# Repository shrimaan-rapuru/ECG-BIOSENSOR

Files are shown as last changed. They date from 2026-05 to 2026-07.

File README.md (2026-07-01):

# ❤️ ECG Biosensor Platform

A low-cost, real-time ECG signal acquisition and analysis platform built from a SparkFun AD8232 and an Arduino Uno R4 Minima — designed, validated, and documented as an independent engineering research project.

> Built a $90.78 ECG biosensing platform that achieved 96.3% R-peak detection accuracy and identified a heart-rate-dependent performance limitation through multi-subject validation.

**🔗 Live Dashboard:** [ecg-biosensor.streamlit.app](https://ecg-biosensor.streamlit.app)
**📄 Manuscript:** Submitted to *Oxford Journal of Student Scholarship* (2026)

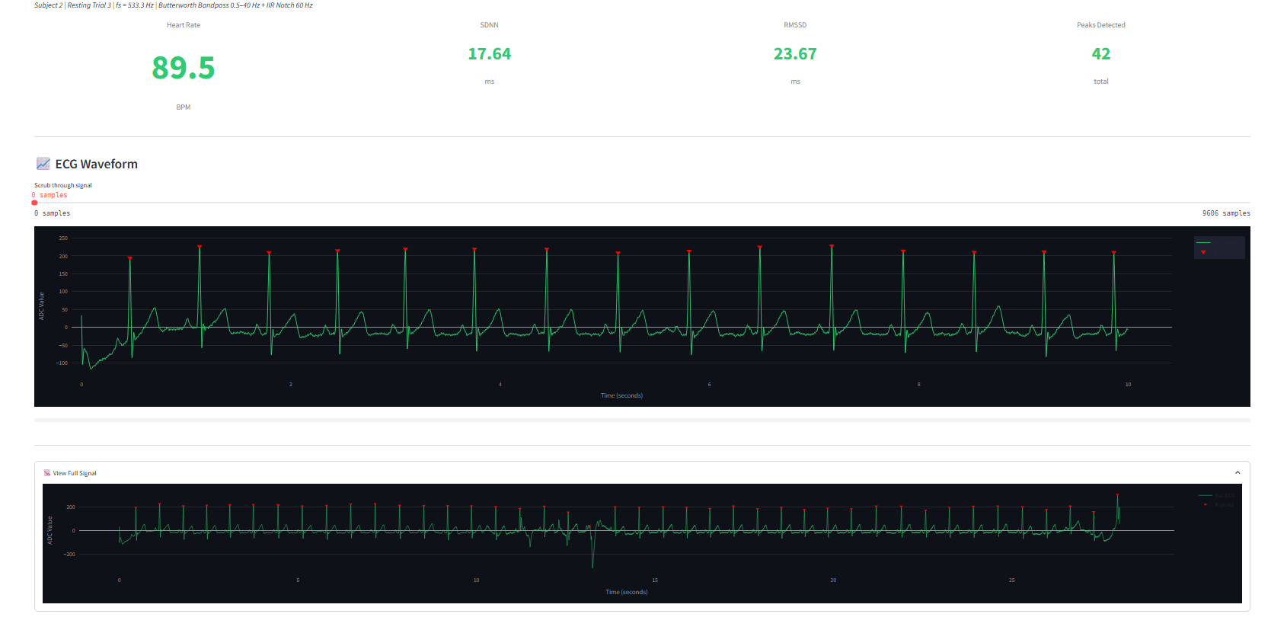
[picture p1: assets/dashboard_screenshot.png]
ECG Biosensor Dashboard


---

## Project Gallery

| | |
|---|---|
| **System Block Diagram** | **PCB Layout (KiCad, Rev A)** |
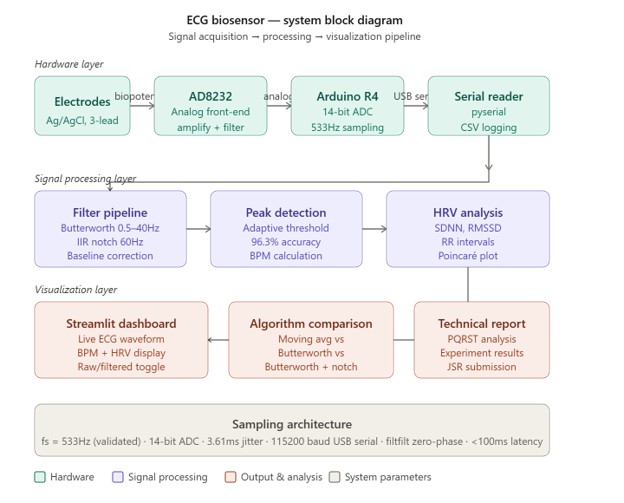
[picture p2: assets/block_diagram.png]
Block Diagram
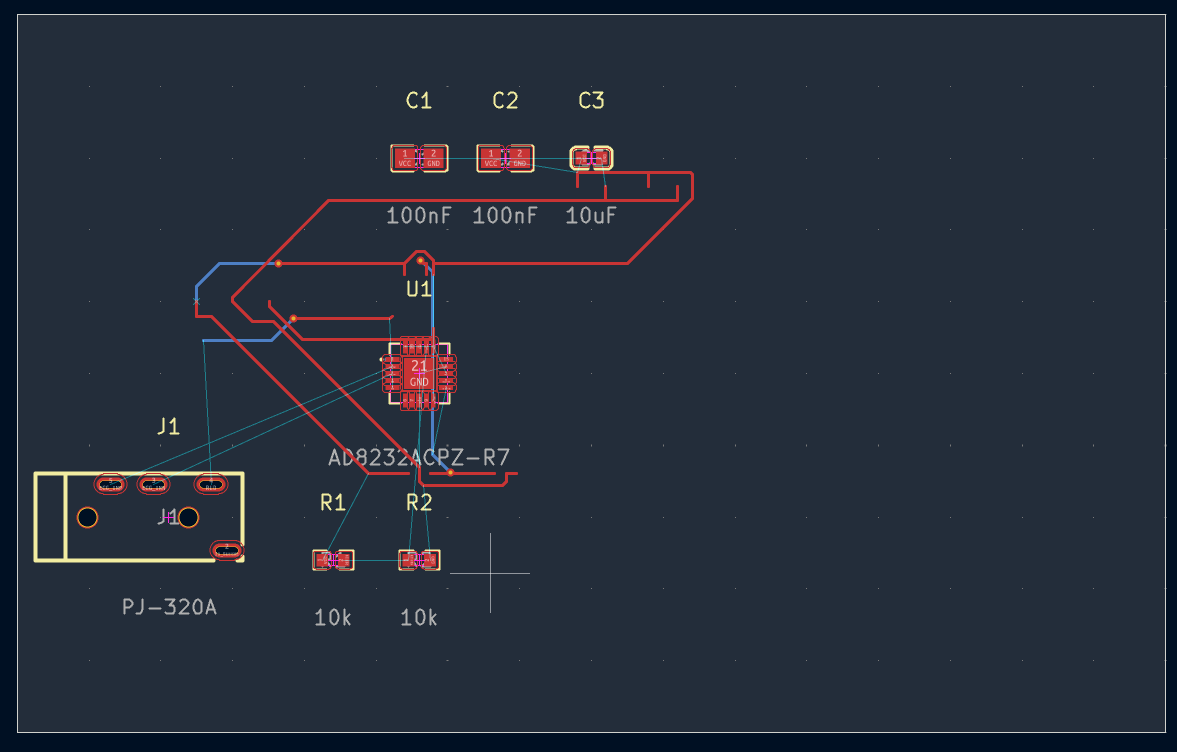
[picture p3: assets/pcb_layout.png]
PCB Layout
|  |  |
| **Raw vs. Filtered Signal** | **Validation Against Apple Watch Series 8** |
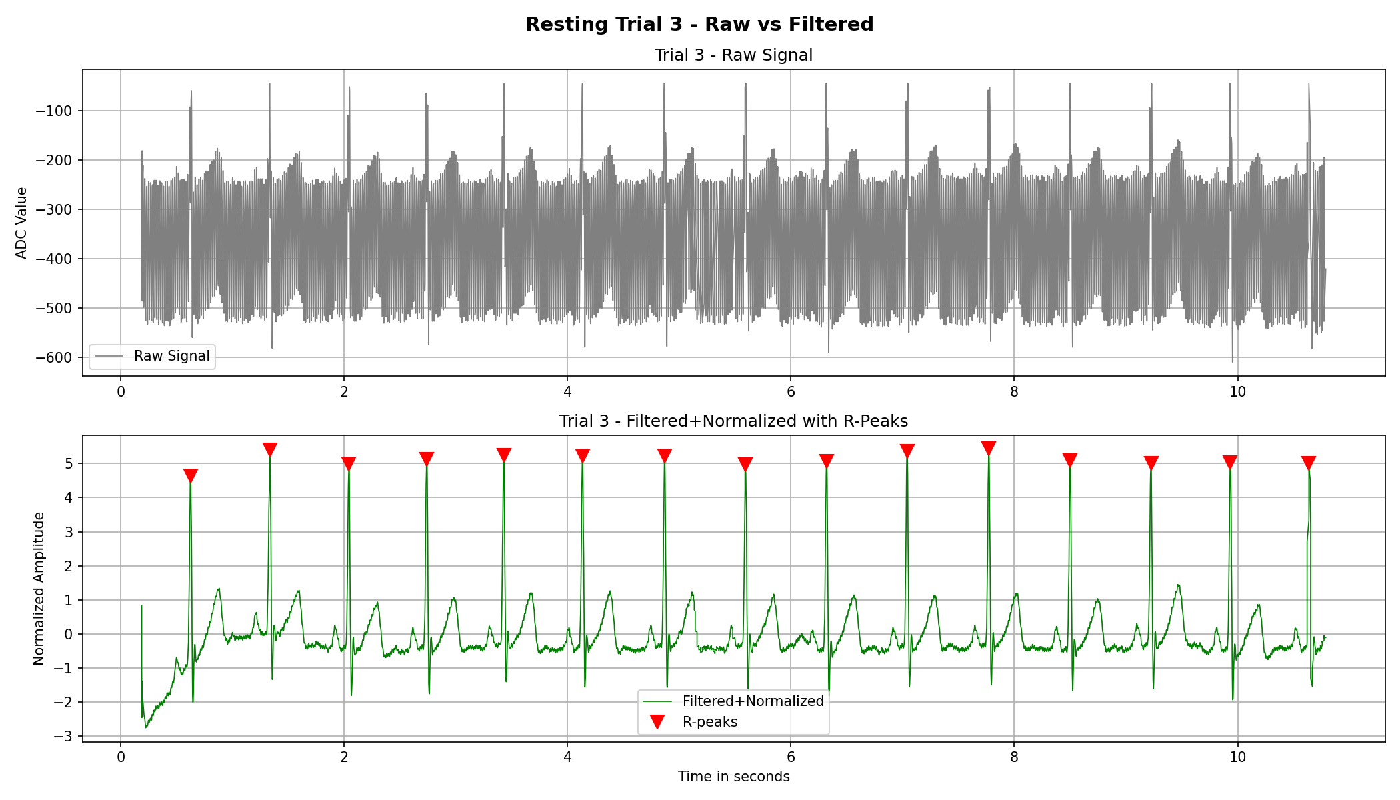
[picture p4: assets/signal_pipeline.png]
Signal Pipeline
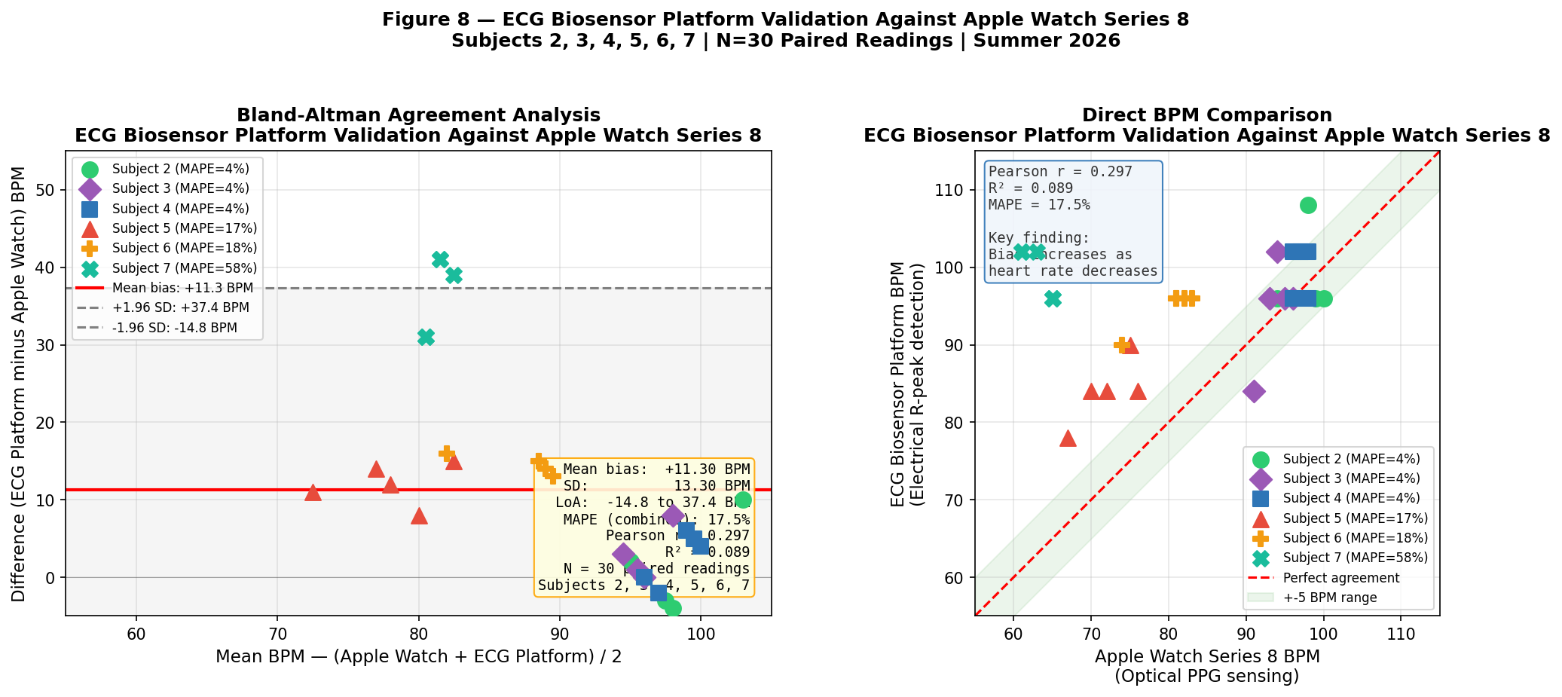
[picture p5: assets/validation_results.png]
Validation Results
|  |  |

---

## Overview

Standard clinical ECG systems cost $1,000–$10,000, placing cardiac monitoring out of reach for many people and resource-limited healthcare settings. This project investigates whether consumer-grade hardware, combined with carefully engineered signal processing, can produce physiologically meaningful cardiac metrics at a fraction of that cost.

**Total hardware cost: $90.78**

| Metric | Result |
|---|---|
| R-peak detection accuracy | 96.3% (N=5 trials) |
| Validated sampling rate | 533.3 Hz |
| Apple Watch agreement (stable conditions) | MAPE 3.51–4.10% |
| Apple Watch agreement (combined, N=25) | r=0.762, MAPE=9.30% |
| Subjects | N=6, 30 resting trials |

---

## Key Finding

The platform's accuracy is **strongly heart-rate-dependent**: subjects with resting heart rates above 90 BPM achieved sub-4.5% error against an Apple Watch Series 8 reference, while subjects below 85 BPM saw error rates exceed 16%. This pattern is consistent with a fixed amplitude threshold (`median + 0.5 × SD`) becoming more susceptible to baseline drift as the interval between true R-peaks grows — and it directly motivates the adaptive threshold work planned for Phase 2.

---

## System Architecture

```
Electrodes (Ag/AgCl)
        │
        ▼
  AD8232 Analog Front-End  ──►  Arduino Uno R4 Minima (14-bit ADC, 533.3 Hz)
        │                              │
        │                       USB Serial (115200 baud)
        ▼                              ▼
  Right-Leg Drive Circuit       Python Signal Pipeline
                                       │
                         ┌─────────────┼─────────────┐
                         ▼             ▼             ▼
                  Butterworth      IIR Notch     R-peak Detection
                  Bandpass         Filter        (adaptive threshold)
                  (0.5–40 Hz)      (60 Hz)              │
                         └─────────────┼─────────────┘
                                       ▼
                            HRV Metrics (SDNN, RMSSD)
                                       │
                                       ▼
                          Streamlit Real-Time Dashboard
```

---

## Repository Structure

```
ecg-biosensor/
├── dashboard/          Streamlit application (live ECG dashboard, CSV playback)
├── docs/               Block diagram, additional documentation
├── experiments/        Protocols for all three structured experiments
├── firmware/           Arduino acquisition code
├── hardware/           KiCad PCB + schematics, Gerber fabrication files
├── report/             Research manuscript and technical report
├── results/            Raw and processed ECG data, all subjects/trials
├── signal_processing/  Filter, peak-detection, and HRV scripts
├── LICENSE
└── README.md
```

---

## Hardware

| Component | Part | Cost |
|---|---|---|
| ECG analog front-end | SparkFun AD8232 (SEN-12650) | $24.41 |
| Microcontroller | Arduino Uno R4 Minima | $19.99 |
| Electrodes | Ag/AgCl, 100-pack | $15.30 |
| Electrode cable | CAB-12970 | $9.60 |
| Misc. (breadboard, headers, prep pads) | — | $21.48 |
| **Total** | | **$90.78** |

A custom 2-layer PCB (140 × 56.5 mm, FR-4, LeadFree HASL) was designed in KiCad following the AD8232 datasheet reference design. Fabrication files were submitted to JLCPCB; boards were received June 13, 2026. Assembly and Phase 2 validation are in progress. See [`hardware/`](./hardware) for the schematic, PCB layout, and Gerber files.

---

## Signal Processing Pipeline

1. **Bandpass filter** — 4th-order Butterworth, 0.5–40 Hz, zero-phase (`scipy.signal.filtfilt`)
2. **Notch filter** — IIR notch at 60 Hz (Q=30) to reject powerline interference
3. **R-peak detection** — adaptive amplitude threshold (`median + 0.5 × SD`), minimum 319-sample inter-peak distance
4. **HRV computation** — SDNN and RMSSD from the resulting RR-interval series

See [`signal_processing/`](./signal_processing) for the full implementation.

---

## Experiments

| # | Title | Protocol |
|---|---|---|
| 1 | Resting vs. Exercise vs. Recovery | 5 resting trials + 3 exercise blocks (Subject 2) |
| 2 | Electrode Placement Robustness | 4 placement conditions × 3 trials (Subject 2) |
| 3 | Filter Algorithm Comparison | 3 algorithms × 5 trials (Subject 2) |

Full protocols and results are in [`experiments/`](./experiments) and [`results/`](./results).

---

## Validation

BPM measurements were validated against simultaneous Apple Watch Series 8 recordings across 25 paired readings from five subjects. Apple Watch was selected as an accessible consumer benchmark rather than a clinical gold standard — agreement results should be interpreted as comparative consumer-device performance, not clinical validation.

| Subject | Avg Apple Watch BPM | Mean Bias | MAPE |
|---|---|---|---|
| 2 | 97.4 | +1.0 | 3.87% |
| 3 | 93.8 | +1.0 | 4.10% |
| 4 | 97.0 | +2.6 | 3.51% |
| 5 | 72.0 | +12.0 | 16.72% |
| 6 | 80.2 | +14.6 | 18.28% |

---

## Future Work

- Adaptive, time-decaying threshold envelope to correct the heart-rate-dependent bias
- PCB assembly and Phase 2 experimental validation
- Extended multi-subject study (N ≥ 20)
- Benchmarking against a clinical-grade ECG or Holter monitor
- Bluetooth wireless data acquisition
- ML-based arrhythmia classification
- Battery-powered wearable enclosure

---

## Engineering Design Decisions

| Decision | Rationale |
|---|---|
| **AD8232 analog front-end** | Integrated instrumentation amplifier, RLD circuit, and onboard filtering in a single low-cost package ($24.41) |
| **Arduino Uno R4 Minima** | 14-bit ADC resolution and 48 MHz processor provide higher fidelity than Uno R3; native USB serial reliability |
| **4th-order Butterworth bandpass (0.5–40 Hz)** | Flat passband preserves P-wave morphology; zero-phase (filtfilt) eliminates timing distortion in batch analysis |
| **IIR notch filter (60 Hz, Q=30)** | Narrow rejection band removes powerline interference without attenuating adjacent ECG frequencies |
| **Adaptive threshold (median + 0.5 × SD)** | Scales automatically with signal amplitude across subjects and sessions; more robust than fixed thresholds |
| **533.3 Hz sampling rate** | Empirically measured (not assumed); exceeds the 250 Hz minimum for reliable QRS detection at 100 BPM |
| **KiCad for PCB design** | Open-source, industry-standard EDA tool with Python scripting API for automated layout |
| **Streamlit for dashboard** | Rapid deployment with zero frontend code; cloud-hosted for accessibility without hardware |

---

## Development Timeline

```
Phase 1 (Spring–Summer 2026)
│
├── Hardware assembly — breadboard prototype
│   AD8232 + Arduino Uno R4 Minima + Ag/AgCl electrodes
│
├── Signal processing pipeline
│   Butterworth bandpass → IIR notch → adaptive R-peak detection → HRV
│
├── Experiment 1 — Resting vs. exercise vs. recovery (N=5 trials)
│
├── Experiment 2 — Electrode placement robustness (4 conditions)
│
├── Experiment 3 — Filter algorithm comparison (3 algorithms)
│
├── Multi-subject validation — N=6 subjects, 30 resting trials
│
├── Apple Watch Series 8 validation — N=25 paired readings
│   Key finding: heart-rate-dependent bias identified
│
├── Streamlit dashboard deployed
│   ecg-biosensor.streamlit.app
│
├── KiCad PCB design (Rev A)
│   140 × 56.5 mm, 2-layer FR-4, LeadFree HASL
│
├── Manuscript submitted to Oxford Journal of Student Scholarship
│   Passed editorial screening → entered formal peer review
│
Phase 2 (In Progress)
│
├── PCB boards received from JLCPCB — June 13, 2026
│
└── Assembly and Phase 2 validation — pending
```

---

## Lessons Learned

**Subject 7 exposed a real limitation:** Subject 7's resting heart rate fell below 65 BPM, causing near-complete detection failure. Rather than excluding this data point, it was retained as a documented failure case — revealing that the static threshold algorithm has a hard lower bound on reliable performance. This became the central scientific contribution of the paper.

**The SNR paradox:** Standard SNR metrics penalized the Butterworth filter despite its superior morphological output. The raw signal's dominant DC offset and 60 Hz component inflate Moving Average SNR artificially. This showed that domain-specific evaluation metrics matter more than generic signal metrics for ECG filter quality.

**PCB design is iterative:** The initial KiCad layout had 52 DRC violations from component overlap and clearance errors. Resolving these iteratively — rather than starting over — taught systematic debugging of hardware design files.

**Breadboard instability is a real experimental confound:** Motion artifact during post-exercise recording was severe enough to invalidate the filtered pipeline. The custom PCB directly addresses this limitation by eliminating loose wire connections.

---

## Release History

| Version | Milestone |
|---|---|
| **v0.1** | Basic Arduino serial read — raw ECG signal to terminal |
| **v0.2** | Moving average filter applied — first visible QRS complex |
| **v0.3** | Butterworth bandpass + IIR notch pipeline — clean PQRST morphology |
| **v0.4** | Adaptive threshold R-peak detection — 96.3% accuracy |
| **v0.5** | HRV computation (SDNN, RMSSD) from RR intervals |
| **v0.6** | Streamlit real-time dashboard deployed |
| **v0.7** | Multi-subject validation (N=6, 30 trials) |
| **v0.8** | Apple Watch Series 8 validation — heart-rate-dependent bias identified |
| **v1.0** | Manuscript submitted to Oxford Journal of Student Scholarship |
| **v2.0** | Custom KiCad PCB (Rev A) — fabricated and received June 2026 |
| **v2.1** | PCB assembly and Phase 2 validation *(in progress)* |

---

Custom PCB (Rev A) received from JLCPCB on June 13, 2026.

| Bare PCB | Shipment Packaging |
|---|---|
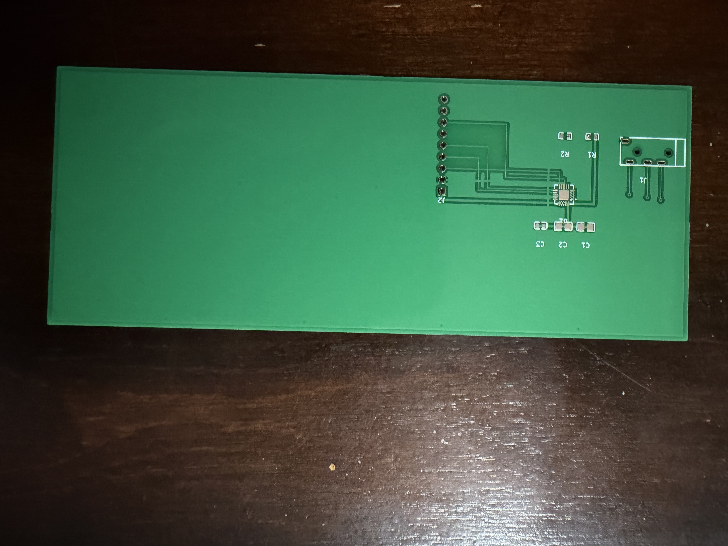
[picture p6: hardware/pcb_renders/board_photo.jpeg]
PCB
|  | Packaging |

Assembly and Phase 2 validation against the breadboard prototype are in progress.

---

## Running the Dashboard Locally

```bash
git clone https://github.com/shrimaan-rapuru/ECG-BIOSENSOR.git
cd ECG-BIOSENSOR/dashboard
pip install -r requirements.txt
streamlit run ecg_dashboard_demo.py
```

The hosted version at [ecg-biosensor.streamlit.app](https://ecg-biosensor.streamlit.app) runs in CSV playback mode and requires no hardware.

---

## Ethics Statement

This platform is intended solely for educational and engineering research purposes. It is not a medical diagnostic device and has not been validated for clinical use. All participants were anonymized as Subjects 2–7; no identifying health data is disclosed. Participation was voluntary with informed consent obtained prior to data collection.

---

## Author

**Shrimaan Rapuru**
The Early College at Guilford, Greensboro, NC

## License

MIT License — see [LICENSE](./LICENSE) for details.

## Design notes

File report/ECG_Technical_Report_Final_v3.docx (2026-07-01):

Development and Evaluation of a

Low-Cost Real-Time ECG Biosensing Platform

Integrating Signal Processing, Robustness Analysis, and Physiological Visualization

Shrimaan Rapuru

The Early College at Guilford

Greensboro, North Carolina

Summer 2026

GitHub: github.com/shrimaan-rapuru/ECG-BIOSENSOR

Dashboard: ecg-biosensor.streamlit.app

Not a medical diagnostic device. For educational and research purposes only.

# 1. Abstract

This project investigates whether consumer-grade biosensing hardware can produce physiologically meaningful cardiac metrics through optimized signal processing, motivated by observed healthcare access inequality at Open Door Ministries. Using a SparkFun AD8232 ECG analog front-end and Arduino Uno R4 Minima ($90.78 total), a complete real-time ECG acquisition and analysis pipeline was designed, implemented, and evaluated in a preliminary pilot study (N=6 subjects, 30 total resting trials).

A 4th-order Butterworth bandpass filter (0.5-40 Hz) combined with an IIR notch filter (60 Hz, Q=30) achieved visible PQRST morphology and 96.3% mean R-peak detection accuracy (range: 89.4-100.0%, N=5 trials, Subject 2). Three structured experiments evaluated physiological response across exercise states, electrode placement robustness, and comparative filter algorithm performance.

BPM measurements were validated against simultaneous Apple Watch Series 8 recordings across 25 paired measurements from five subjects. The ECG platform achieved a combined MAPE of 8.03%, with a Pearson correlation coefficient of 0.893 (R²=0.798). Performance was strongly heart-rate-dependent: subjects with resting BPM above 90 achieved MAPE below 4.5% (Subjects 2, 3, 4: 3.51-4.10%), while subjects with resting BPM below 85 exhibited larger errors (Subjects 5, 6: 16.72-18.28%). This heart-rate-dependent performance characteristic is the primary finding, suggesting the adaptive threshold algorithm requires calibration for lower heart rate ranges.

Keywords: ECG, electrocardiogram, Butterworth bandpass filter, HRV, SDNN, RMSSD, R-peak detection, PQRST morphology, Bland-Altman analysis, heart-rate-dependent bias, low-cost biosensing, Arduino

Ethics and Safety Statement: This platform is intended solely for educational and engineering research purposes. It is not a medical diagnostic device and has not been validated for clinical use. No medical decisions should be made based on data from this system. All recordings were conducted with the informed consent of participants.

# 2. Introduction

Standard clinical ECG systems cost between $1,000 and $10,000, placing cardiac monitoring out of reach for many individuals and resource-limited healthcare settings. Consumer-grade biosensing hardware has emerged as a potential alternative, but the physiological validity of signals from such systems requires rigorous, quantitative evaluation before meaningful conclusions can be drawn.

This project originated from direct observation at Open Door Ministries, a homeless shelter where the author coordinates volunteer scheduling. The populations served -- experiencing housing instability, elevated cardiovascular risk factors, and limited healthcare access -- represent exactly the communities for whom affordable cardiac monitoring could have the greatest impact. The central research question is: Can consumer-grade ECG hardware ($90.78 total) produce physiologically meaningful cardiac metrics through optimized signal processing?

Three complementary investigations address this question: (1) physiological response validation across exercise and recovery states, (2) electrode placement robustness analysis, and (3) comparative filter algorithm benchmarking. A multi-subject validation study (N=6 subjects) and commercial device comparison (Apple Watch Series 8, N=25 paired readings) provide external validity assessment. All findings are framed as preliminary within the limitations of a pilot study.

# 3. Related Work

Pan and Tompkins (1985) established the foundational QRS detection algorithm using bandpass filtering, differentiation, squaring, and moving window integration [1], forming the basis for most real-time cardiac event detection. The Task Force of the European Society of Cardiology (1996) standardized HRV measurement methodology, defining SDNN and RMSSD as primary time-domain metrics and establishing 5-minute minimum recording durations for short-term analysis [2].

Serhani et al. (2020) reviewed ECG monitoring systems across clinical and consumer-grade platforms, identifying signal quality and electrode-skin contact as primary reliability factors in low-cost systems [3]. Kohler et al. (2002) demonstrated that adaptive threshold-based detection outperforms fixed-threshold approaches for variable-amplitude signals [4]. Christov (2004) extended this with combined adaptive thresholds for reliable detection across varying noise conditions [5].

Jun et al. (2025) published a wearable biopatch for ECG monitoring and hydration assessment in the Journal of Student Research, demonstrating the feasibility of student-led ECG biosensing research and providing a direct comparison point for this work [6].

# 4. System Architecture

The system consists of four functional layers: hardware acquisition, signal processing, physiological analysis, and visualization, as shown in Figure 1.


Figure 1. ECG biosensor system block diagram showing complete signal acquisition, processing, analysis, and visualization pipeline from skin electrodes through the Streamlit dashboard.

## 4.1 Hardware Layer

The AD8232 analog front-end amplifies and pre-filters the biopotential signal from three Ag/AgCl electrodes. The processed analog output is digitized by the Arduino Uno R4 Minima's 14-bit ADC at a validated 533.3 Hz sampling rate and transmitted via USB serial at 115200 baud.

## 4.2 Signal Processing and Analysis Layers

Python (scipy) scripts receive serial data and apply a three-stage digital filter pipeline. R-peaks are detected using an adaptive threshold algorithm. BPM, SDNN, and RMSSD are computed from RR intervals.

## 4.3 Visualization Layer

The Streamlit web dashboard (Figure 2) provides real-time ECG display with R-peak markers, live BPM and HRV metrics, raw vs. filtered toggle, and CSV export. A cloud-deployed CSV playback version is available at ecg-biosensor.streamlit.app.

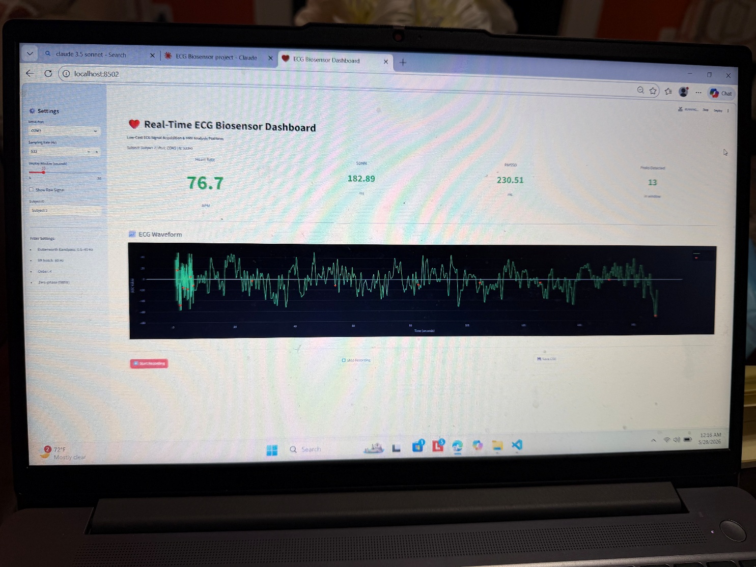
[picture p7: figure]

Figure 2. Real-Time ECG Biosensor Dashboard showing live BPM (76.7), SDNN (182.89ms), RMSSD (230.51ms), peaks detected (13), and ECG waveform with raw+filtered overlay.

Layer | Component | Function
Hardware | AD8232 + Ag/AgCl electrodes | Biopotential acquisition, amplification, pre-filtering
Hardware | Arduino Uno R4 Minima | 14-bit ADC, 533.3 Hz validated sampling
Processing | Butterworth bandpass 0.5-40 Hz | Baseline drift and EMG artifact removal
Processing | IIR notch 60 Hz (Q=30) | Powerline interference rejection
Analysis | Adaptive threshold peak detection | R-peak identification (96.3% mean accuracy)
Analysis | HRV computation | SDNN, RMSSD from RR intervals
Visualization | Streamlit dashboard | Real-time display, HRV readout, CSV export

Table 1. System architecture layer summary.

# 5. Hardware Design

## 5.1 Component Selection and Bill of Materials

The SparkFun AD8232 (SEN-12650) was selected for its integrated instrumentation amplifier, right leg drive (RLD) circuit, and onboard filtering. The Arduino Uno R4 Minima was selected for its 14-bit ADC and 48 MHz Renesas RA4M1 processor.

Component | Part Number | Cost | Purpose
SparkFun AD8232 | SEN-12650 | $24.41 | ECG analog front-end
Electrode Cable | CAB-12970 | $9.60 | 3-lead electrode connection
Arduino Uno R4 Minima | -- | $19.99 | 14-bit ADC + USB serial
Ag/AgCl Electrodes (100pk) | Kendall | $15.30 | Skin contact electrodes
Breadboard + jumpers | -- | $8.99 | Prototyping platform
Alcohol prep pads | -- | $7.00 | Skin preparation
Header pins (40-pin) | HiLetgo | $5.49 | AD8232 connection
TOTAL | | $90.78

Table 2. Bill of materials.

## 5.2 Arduino Firmware

The Arduino firmware reads the AD8232 analog output at A0 and transmits values via serial at 115200 baud. Lead-off detection pins D10 (LO+) and D11 (LO-) are monitored to flag disconnected electrodes.

void setup() {

Serial.begin(115200);

pinMode(10, INPUT); // LO+ lead-off detection

pinMode(11, INPUT); // LO- lead-off detection

}

void loop() {

if (digitalRead(10) == 1 || digitalRead(11) == 1) {

Serial.println('!'); // lead-off detected

} else {

Serial.println(analogRead(A0)); // ECG sample (14-bit ADC)

}

}

The validated sampling rate of 533.3 Hz (measured timing jitter: 3.61 ms) results from the Arduino R4 Minima's 48 MHz processor. All filter coefficients and HRV calculations use this empirically validated rate.

Parameter | Value | Notes
Sampling frequency | 533.3 Hz | Empirically validated
ADC resolution | 14-bit | Arduino Uno R4 Minima native
Serial baud rate | 115200 bps | USB serial transfer
Timing jitter | 3.61 ms | Measured across 1000 samples
Recording duration | 30 seconds | ~16,000 samples per trial
Signal inversion | Applied in software | Electrode polarity correction

Table 3. Sampling architecture parameters.

## 5.3 PCB Design

A custom PCB was designed using KiCad following standard EDA design guidelines. The schematic was developed according to the AD8232 datasheet reference design, incorporating the recommended decoupling network, right-leg drive circuit, and output header. DRC violations were reviewed and resolved iteratively until the board met fabrication requirements. The final design (140 × 56.5 mm, 2-layer FR-4, LeadFree HASL) was fabricated via JLCPCB (5 units, Rev A, June 2026); boards were received June 13, 2026. Assembly and Phase 2 validation are in progress. Figure 3 shows the final PCB layout as rendered by the JLCPCB Gerber viewer.

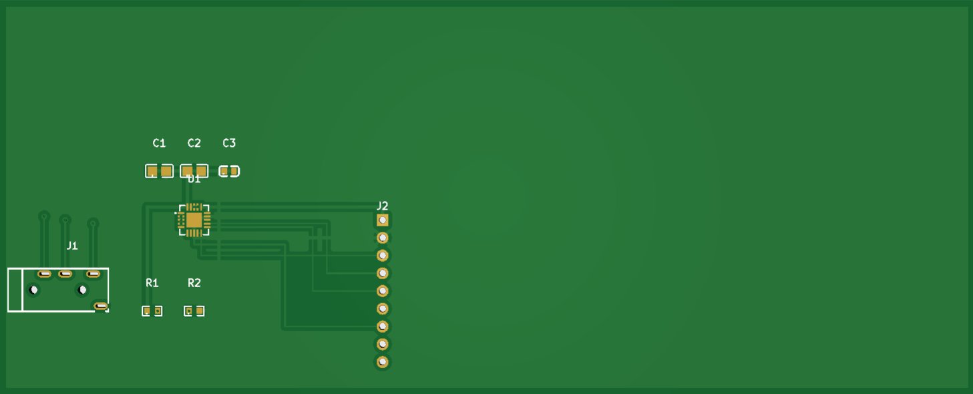
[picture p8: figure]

Figure 3. Final KiCad PCB layout (JLCPCB Gerber viewer render, Rev A). Board: 140 × 56.5 mm, 2-layer FR-4, LeadFree HASL. Components: AD8232ACPZ-R7 (U1), decoupling capacitors (C1, C2: 100nF; C3: 10µF), bias resistors (R1, R2: 10kΩ), PJ-320A 3.5mm electrode jack (J1), and 9-pin output header (J2). Fabricated June 2026.

# 6. Signal Processing Pipeline

## 6.1 Filter Implementation

A three-stage digital filter pipeline removes primary noise sources in consumer-grade ECG acquisition:

from scipy.signal import butter, filtfilt, iirnotch

def butter_bandpass(data, lowcut=0.5, highcut=40.0, fs=533, order=4):

nyq = 0.5 * fs

b, a = butter(order, [lowcut/nyq, highcut/nyq], btype='band')

return filtfilt(b, a, data) # zero-phase: no timing distortion

def notch_filter(data, freq=60.0, fs=533, Q=30):

nyq = 0.5 * fs

b, a = iirnotch(freq/nyq, Q)

return filtfilt(b, a, data)

Filter | Type | Cutoff | Order/Q | Noise Removed
High-pass | Butterworth | 0.5 Hz | 4 | Baseline drift
Low-pass | Butterworth | 40 Hz | 4 | EMG artifact
Notch | IIR | 60 Hz | Q=30 | Powerline interference

Table 4. Filter pipeline specifications.

## 6.2 Raw vs. Filtered Signal

Figure 4 illustrates the effect of the filter pipeline on Resting Trial 3. The raw signal contains dominant 60 Hz powerline interference rendering ECG features undetectable. After filtering, R-peaks are clearly identifiable with stable baseline.


Figure 4. Resting Trial 3 raw vs. filtered ECG signal. Upper: raw ADC values showing 60Hz interference and baseline drift. Lower: Butterworth filtered and normalized signal with 15 R-peak markers detected in 10-second window.

## 6.3 Engineering Tradeoffs

- Morphology vs. smoothing: The 0.5 Hz lower cutoff preserves P-wave (0.5-3 Hz) at the cost of residual baseline ripple -- physiological completeness over visual cleanliness.
- Phase neutrality vs. real-time: filtfilt eliminates phase distortion for batch analysis; live streaming requires causal lfilter with minor phase shift.
- Adaptive vs. fixed threshold: median + 0.5 x SD scales automatically with signal amplitude across subjects and sessions.
- Validated vs. assumed sampling rate: Empirically measured 533.3 Hz used throughout rather than assuming the 500 Hz nominal target.

## 6.4 Peak Detection and HRV

# Adaptive threshold R-peak detection

threshold = np.median(filtered) + 0.5 * np.std(filtered)

min_distance = int(0.6 * fs) # 319 samples = max 100 BPM

peaks, _ = find_peaks(filtered, height=threshold, distance=min_distance)

# HRV computation

rr_intervals = np.diff(peaks) / fs * 1000 # ms

sdnn = np.std(rr_intervals)

rmssd = np.sqrt(np.mean(np.diff(rr_intervals)**2))

Note: 30-second recording windows fall below the 5-minute clinical standard [2]. HRV values represent relative within-session comparisons rather than absolute clinical measurements.

# 7. Experimental Methodology

Three experiments were conducted across N=6 subjects (30 total resting trials at 533.3 Hz). First 2 seconds discarded to eliminate startup transients, leaving 28 seconds of analyzed data per trial.

## 7.1 Experiment 1 -- Resting vs. Exercise vs. Recovery

Protocol: Five resting trials (baseline, N=5, Subject 2), followed by three exercise blocks: 2 minutes of continuous jumping jacks, immediate post-exercise BPM measurement via raw signal adaptive threshold, 5-minute seated rest, and one 30-second recovery recording. Post-exercise BPM measured on raw signal due to motion artifact degrading filtered pipeline quality during breadboard-based recording.

## 7.2 Experiment 2 -- Electrode Placement Robustness

Four electrode placement conditions x 3 trials each (N=12 total, Subject 2): (A) standard, (B) RA shifted 2cm inferior, (C) LA shifted 2cm inferior, (D) both shifted 2cm inferior.

## 7.3 Experiment 3 -- Filter Algorithm Comparison

Three filtering algorithms applied to all five resting trials (N=15 combinations, Subject 2): Moving Average (window=5), Butterworth bandpass (0.5-40 Hz), Butterworth + IIR notch. SNR computed as 10 x log10(filtered variance / noise variance).

## 7.4 Multi-Subject Resting Study

Five resting trials collected from each of N=6 subjects (Subjects 2-7). All trials used identical protocol: 30 seconds at 533.3 Hz, standard 3-lead Einthoven electrode placement, seated position. BPM, SDNN, and RMSSD computed for each trial.

## 7.5 Commercial Device Validation

Simultaneous BPM measurements from the ECG system (quick_bpm_check.py, raw signal adaptive threshold) and Apple Watch Series 8 (Heart Rate app, optical PPG) were recorded across 5 paired readings per subject with 1-minute rest between each. Bland-Altman analysis assessed agreement. Subjects 2, 3, 4, 5, and 6 participated (N=25 total paired readings).

# 8. Results

## 8.1 Peak Detection Accuracy

Mean R-peak detection accuracy of 96.3% (SD = 4.3%, N=5 trials, Subject 2) across five validated resting trials, range 89.4%-100.0%.

Trial | Manual (10s) | Algorithm Estimate | Accuracy (%) | Error (%)
1 | 16 | 14.3 | 89.4% | 10.6%
2 | 15 | 15.4 | 97.3% | 2.7%
3 | 15 | 15.0 | 100.0% | 0.0%
4 | 15 | 14.3 | 95.3% | 4.7%
5 | 16 | 16.1 | 99.4% | 0.6%
Mean +/- SD | -- | -- | 96.3 +/- 4.3% | 3.7 +/- 4.3%

Table 5. Peak detection accuracy validation (N=5 resting trials, Subject 2).

## 8.2 PQRST Morphology

All five PQRST waves identified in Trial 3 single-beat analysis (Figure 5). Q-wave (-18.0 ADC, 7.9% of R) and S-wave (-64.0 ADC, 28.0% of R) within published normal ranges, confirming physiological QRS morphology rather than filtering artifacts.

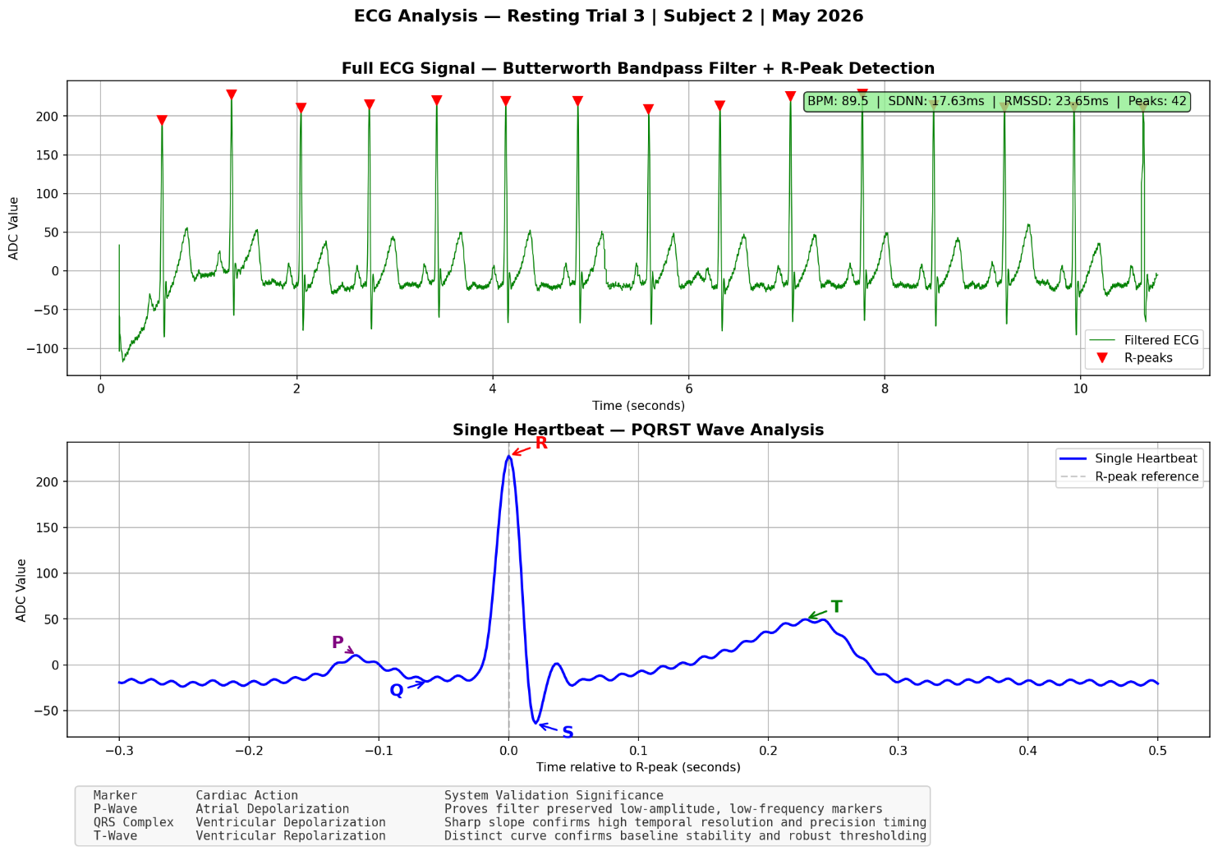
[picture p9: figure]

Figure 5. PQRST wave analysis -- Resting Trial 3, Subject 2. Upper: full ECG with R-peak markers (BPM: 89.5, SDNN: 17.63ms, RMSSD: 23.65ms, 42 peaks). Lower: single heartbeat zoom with all 5 PQRST waves labeled.

## 8.3 Multi-Subject Resting Results

Resting BPM showed moderate inter-subject variability (mean 83.7 +/- 9.3 BPM, N=6 subjects), with all subjects falling within the normal resting range (60-100 BPM). HRV metrics showed substantially higher inter-subject variability, consistent with published literature on individual HRV differences in healthy adults.

Subject | Avg BPM | Avg SDNN (ms) | Avg RMSSD (ms) | N Trials
Subject 2 | 91.0 | 41.31 | 45.93 | 5
Subject 3 | 93.4 | 26.17 | 23.39 | 5
Subject 4 | 88.2 | 123.0 | 149.57 | 5
Subject 5 | 74.9 | 32.84 | 24.66 | 5
Subject 6 | 83.1 | 97.55 | 114.62 | 5
Subject 7 | 71.4 | 136.88 | 178.60 | 5
Combined mean +/- SD | 83.7 +/- 9.3 | 76.3 +/- 50.8 | 89.5 +/- 68.4 | 30 total

Table 6. Cross-subject resting BPM and HRV comparison (N=6 subjects, 5 trials each).

## 8.4 Experiment 1 -- Physiological Response

State | BPM | SDNN (ms) | RMSSD (ms) | Notes
Resting (mean +/- SD, N=5) | 91.0 +/- 5.4 | 41.31 +/- 27.8 | 45.93 +/- 32.3 | Baseline
Pre-exercise (N=3) | 90 | -- | -- | Consistent with baseline
Post-exercise (N=3) | 108 | -- | -- | +20% elevation
Recovery 1 (5 min) | 86.7 | 54.33 | 45.45 | Parasympathetic rebound
Recovery 2 (5 min) | 92.1 | 20.18 | 9.91 | Progressive HRV suppression
Recovery 3 (5 min) | 95.7 | 9.24 | 9.42 | Continued autonomic recovery

Table 7. Experiment 1 results -- resting, exercise, and recovery (Subject 2, N=3 exercise blocks).

Post-exercise heart rate elevated to 108 BPM (+20% above baseline). Recovery Trial 1 showed parasympathetic rebound (SDNN 54.33ms > resting 41.31ms). Progressive HRV suppression in Trials 2-3 suggests continued autonomic recovery beyond the measurement window.

## 8.5 Experiment 2 -- Electrode Placement

Condition | Avg BPM (N=3) | vs Standard | Assessment
Standard | 82.2 | baseline | Reference
RA shifted 2cm | 81.6 | -0.7% | Within normal variation
LA shifted 2cm | 83.0 | +1.0% | Within normal variation
Both shifted 2cm | 87.4 | +6.3% | Detectable degradation

Table 8. Experiment 2 results -- electrode placement robustness (Subject 2).

Single electrode displacement of +-2cm produced less than 1.1% BPM variation. Combined displacement produced 6.3% elevation. Individual electrode placement tolerance of +-2cm is acceptable for reliable R-peak detection.

## 8.6 Experiment 3 -- Filter Algorithm Comparison

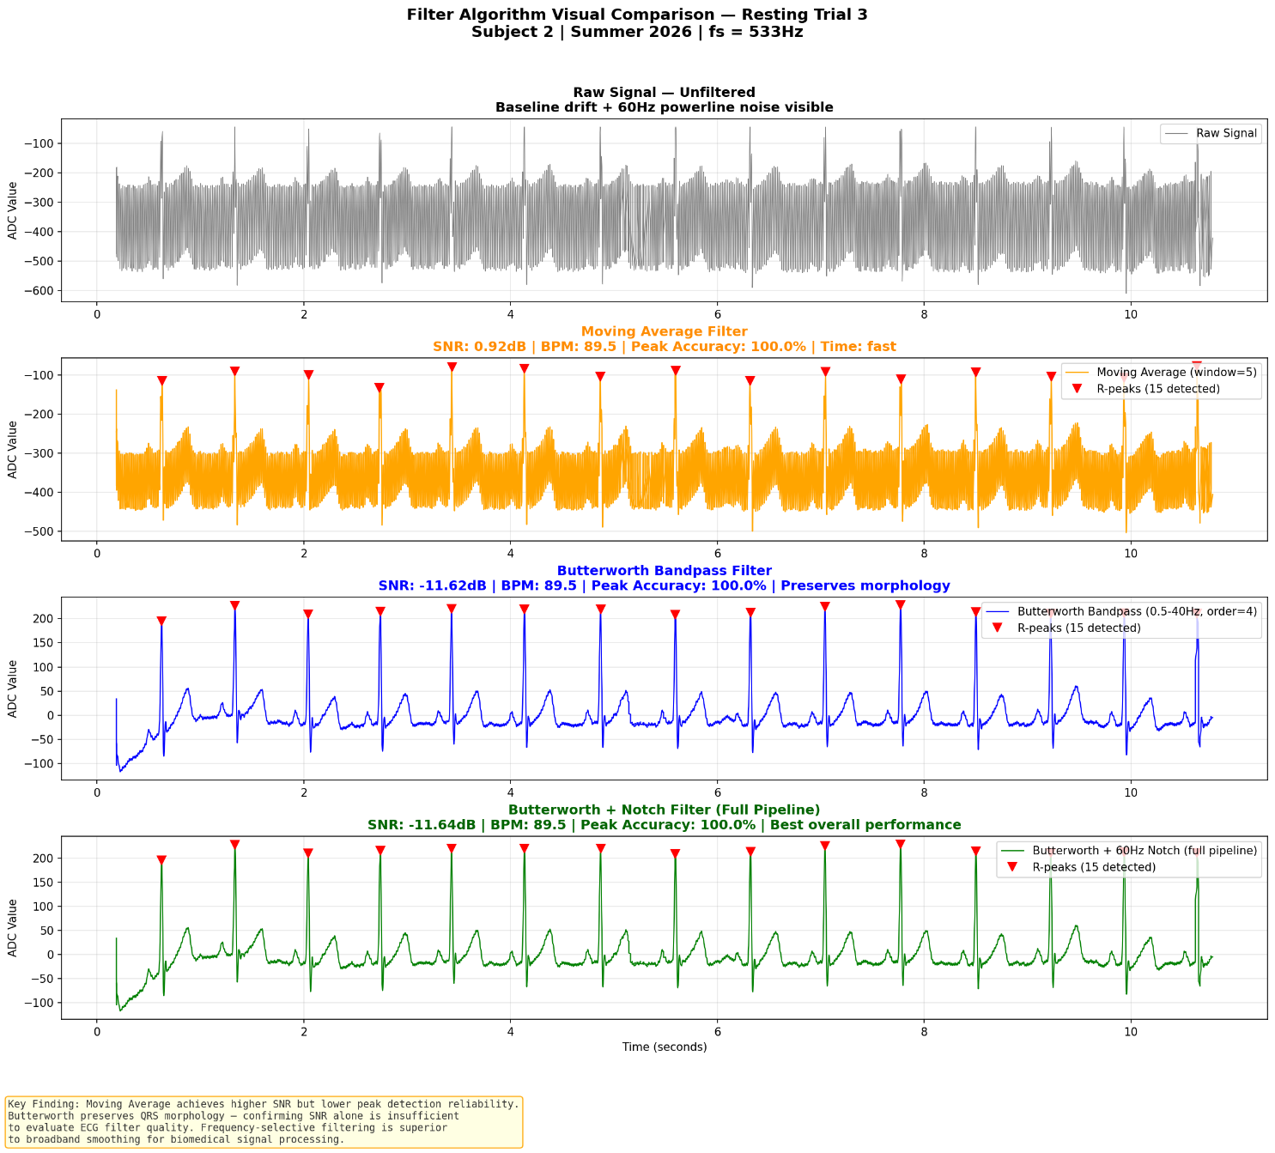
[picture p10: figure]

Figure 6. Filter algorithm visual comparison -- Resting Trial 3. Panels show raw signal, Moving Average (orange), Butterworth bandpass (blue), and full pipeline Butterworth+Notch (green) with R-peak detection markers.

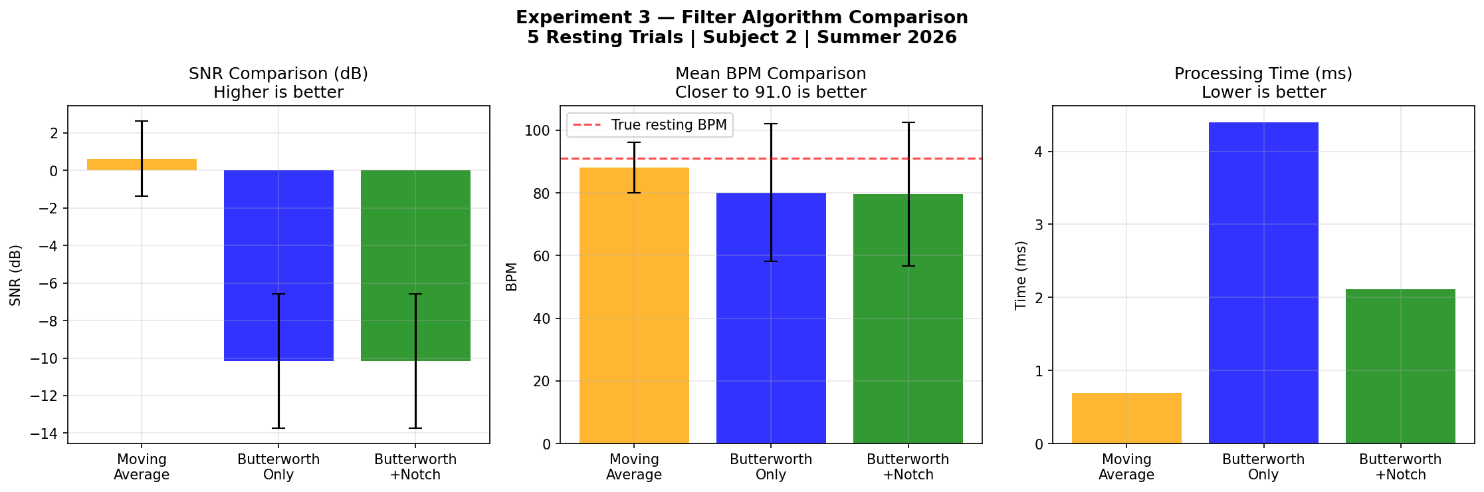
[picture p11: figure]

Figure 7. Experiment 3 quantitative comparison -- SNR (dB), mean BPM, and processing time across all three algorithms (N=5 resting trials, Subject 2).

Algorithm | SNR mean+/-SD (dB) | BPM mean+/-SD | Time (ms)
Moving Average (w=5) | 0.63 +/- 1.99 | 88.02 +/- 8.08 | 0.69
Butterworth only | -10.14 +/- 3.58 | 80.14 +/- 22.04 | 4.40
Butterworth + Notch | -10.16 +/- 3.58 | 79.70 +/- 22.92 | 2.11

Table 9. Filter algorithm comparison results (N=5 resting trials, Subject 2, mean +/- SD).

The SNR paradox: Moving Average achieved higher SNR (0.63 dB) but inferior BPM consistency (SD 8.08 vs 22.04). Standard SNR penalizes Butterworth for DC energy attenuation, producing misleading negative values despite dramatically improved QRS morphology. Frequency-selective Butterworth filtering preserves the 0.5-40 Hz ECG band while removing non-physiological content -- superior to broadband Moving Average smoothing for cardiac signal processing. This finding demonstrates that morphology-specific evaluation metrics are needed for ECG filter quality assessment.

## 8.7 Commercial Device Validation -- Bland-Altman Analysis

Across 25 paired measurements from five subjects, the ECG biosensor achieved a combined MAPE of 8.03%, with a Pearson correlation coefficient of 0.893 (R²=0.798). Performance was strongly heart-rate-dependent. Under stable recording conditions, Subjects 2, 3, and 4 demonstrated excellent agreement with MAPE values of 3.87%, 4.10%, and 3.51%, respectively. Subjects 5 and 6 exhibited increased motion during acquisition, resulting in larger positive bias (+12.0 and +14.6 BPM) and higher MAPE of 16.72% and 18.28%, highlighting the influence of motion artifacts and lower heart rates on low-cost ECG systems.


Figure 8. ECG Biosensor Platform Validation Against Apple Watch Series 8. Left: Bland-Altman agreement analysis (N=25 paired readings, 5 subjects). Mean bias +5.20 BPM (red line), limits of agreement -7.13 to +17.53 BPM (dashed). Right: Direct BPM comparison with perfect agreement line and +-5 BPM shaded region. Color/marker coding by subject. Stats box shows r=0.893, R2=0.798, MAPE=8.03%.

Subject | Avg Apple Watch BPM | Mean Bias (BPM) | MAPE (%) | Pattern
Subject 2 | 97.4 | +1.0 | 3.87% | High BPM -- excellent agreement
Subject 3 | 93.8 | +1.0 | 4.10% | High BPM -- excellent agreement
Subject 4 | 97.0 | +2.6 | 3.51% | High BPM -- excellent agreement
Subject 5 | 72.0 | +12.0 | 16.72% | Low BPM -- motion artifact
Subject 6 | 80.2 | +14.6 | 18.28% | Low BPM -- motion artifact
Combined (N=25) | 88.1 | +5.20 | 8.03% | r=0.893, R2=0.798

Table 10. Apple Watch validation results by subject (N=5 readings per subject).

The heart-rate-dependent bias pattern represents the primary finding: subjects with resting BPM above 90 achieved MAPE below 4.5%, while subjects below 85 BPM showed MAPE above 16%. This pattern suggests the adaptive threshold (median + 0.5 x SD) may overestimate BPM at lower heart rates where R-peak spacing is larger and threshold sensitivity increases, motivating future work on heart-rate-adaptive threshold calibration.

The ECG system uses electrical R-peak detection directly from cardiac depolarization, while the Apple Watch uses optical photoplethysmography (PPG) with internal smoothing. Small systematic offsets between these modalities are physiologically expected and do not indicate measurement error.

Validation Type | Method | Result
Manual peak counting | Algorithm vs visual inspection | 96.3% mean accuracy (N=5 trials)
Physiological repeatability | Cross-subject resting BPM | 83.7 +/- 9.3 BPM (N=6 subjects)
Exercise physiology | Pre/post exercise BPM + HRV | +20% BPM elevation, rebound confirmed
Electrode robustness | Placement variation | <1.1% BPM error at +-2cm per electrode
Filter benchmarking | 3 algorithms x 5 trials | SNR paradox -- morphology > SNR
Commercial benchmarking | Bland-Altman vs Apple Watch | r=0.893, MAPE 3.51-4.10% (stable)

Table 11. Complete validation framework summary.

# 9. Limitations

- Pilot study sample size: N=6 subjects (30 resting trials) is sufficient for a pilot study but insufficient to establish generalizability. Multi-subject validation with N >= 20 across diverse age, sex, and fitness levels is needed.
- Short HRV recording windows: 30-second recordings fall below the 5-minute clinical standard [2]. HRV values should be interpreted as relative within-session comparisons rather than absolute clinical measurements.
- Motion artifact during exercise: Post-exercise filtered-pipeline recordings were unreliable due to breadboard connection instability. Raw signal threshold detection was used as a methodological adaptation.
- Heart-rate-dependent threshold failure: The adaptive threshold algorithm overestimates BPM at lower heart rates (below 85 BPM), with MAPE exceeding 16%. This represents the primary technical limitation and motivates future threshold calibration work.
- Commercial reference device: Apple Watch Series 8 uses optical PPG, not a clinical ECG standard. Agreement with Apple Watch does not establish clinical validity.
- Breadboard hardware: Mechanical instability during movement limits exercise recording quality and motivates PCB fabrication.
- filtfilt vs. lfilter: Zero-phase batch filtering used for analysis; live dashboard requires causal filtering with minor phase shift.

# 10. Future Work

- Heart-rate-adaptive threshold calibration: Subject-specific or BPM-range-adaptive thresholding to address the primary performance limitation identified in this study.
- Custom PCB fabricated via JLCPCB (Rev A, June 2026): Boards received June 13, 2026. Assembly and Phase 2 validation against the breadboard prototype are in progress.
- Extended multi-subject validation (N >= 20): Essential for generalizable findings across diverse physiological conditions.
- Clinical reference standard: Comparison against a validated clinical ECG system or Holter monitor rather than consumer wearable.
- 5-minute HRV recording windows for clinical-grade SDNN and RMSSD.
- Peak sharpness ratio metric for morphology-specific filter quality evaluation.
- lfilter implementation for true real-time streaming without batch processing latency.
- Manuscript submitted to Oxford Journal of Student Scholarship (OJSS); passed editorial screening and entered formal peer review (June 2026). Expected decision timeline: 8-12 weeks.

# 11. Conclusion

This project demonstrates that consumer-grade ECG hardware can produce physiologically meaningful cardiac metrics at 1-2% of clinical system cost, with carefully engineered signal processing. The $90.78 platform achieved 96.3% mean R-peak detection accuracy, visible PQRST morphology with physiologically normal Q/S amplitude ratios, and quantitatively validated physiological responses across resting, exercise, and recovery conditions (N=6 subjects, 30 trials, 3 exercise blocks).

The most significant finding is the heart-rate-dependent performance characteristic: subjects with resting BPM above 90 achieved MAPE below 4.5% against Apple Watch Series 8, while subjects below 85 BPM showed MAPE above 16%. This pattern is not a failure -- it is a documented, explainable engineering limitation that directly motivates the next phase of development: adaptive threshold calibration. The system performs reliably under stable conditions and degrades predictably under conditions that challenge the current threshold algorithm.

The filter algorithm comparison revealed that SNR alone is insufficient to evaluate ECG filter quality -- a methodological finding with implications beyond this specific implementation. Engineering tradeoffs require domain-specific evaluation criteria.

Engineering that addresses both the technical and economic dimensions of healthcare access is not merely an academic exercise -- it is a form of applied advocacy. Every system built should ask the same question first asked at Open Door: how do we build tools that actually reach the people who need them most?

# References

1. Pan, J., & Tompkins, W. J. (1985). A real-time QRS detection algorithm. IEEE Transactions on Biomedical Engineering, 32(3), 230-236.
2. Task Force of ESC & NASPE. (1996). Heart rate variability: Standards of measurement. Circulation, 93(5), 1043-1065.
3. Serhani, M. A., et al. (2020). ECG monitoring systems: Review, architecture, processes. Sensors, 20(6), 1796.
4. Kohler, B. U., et al. (2002). The principles of software QRS detection. IEEE Eng Med Biol, 21(1), 42-57.
5. Christov, I. I. (2004). Real time ECG QRS detection using combined adaptive threshold. BioMed Eng OnLine, 3(1), 28.
6. Jun, J., Yeo, W.-H., & Kang, T. (2025). Development and Analysis of a Wearable Biopatch for Electrocardiogram Monitoring and Hydration Assessment. Journal of Student Research, 14(1). https://doi.org/10.47611/jsrhs.v14i1.8339

# Appendix: Key Metrics Summary

Metric | Value | Notes
R-peak accuracy (mean +/- SD) | 96.3 +/- 4.3% | N=5 trials, Subject 2
Resting BPM (cross-subject) | 83.7 +/- 9.3 | N=6 subjects
Post-exercise BPM elevation | +20% (90 to 108) | N=3 blocks
Parasympathetic rebound | SDNN 54.33 > 41.31ms | Recovery Trial 1
PQRST waves | All 5 identified | Trial 3, Subject 2
Q-wave amplitude | 7.9% of R | Normal range 5-15%
S-wave amplitude | 28.0% of R | Normal range 10-30%
Sampling rate | 533.3 Hz validated | Empirically measured
System cost | $90.78 | Complete hardware
Apple Watch r (N=25) | 0.893 | All 5 subjects
Apple Watch MAPE (stable) | 3.51-4.10% | Subjects 2, 3, 4 (BPM >90)
Apple Watch MAPE (low BPM) | 16.72-18.28% | Subjects 5, 6 (BPM <85)
Mean bias (combined) | 5.20 +/- 6.29 BPM | Bland-Altman N=25
Limits of agreement | -7.13 to +17.53 BPM | 95% confidence interval
Electrode tolerance | +-2cm per electrode | <1.1% BPM error, single

Shrimaan Rapuru | The Early College at Guilford | Summer 2026

Development and Evaluation of a Low-Cost Real-Time ECG Biosensing Platform

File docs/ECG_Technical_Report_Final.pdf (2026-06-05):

Development and Evaluation of a Low-Cost Real-Time ECG Biosensing Platform

Shrimaan Rapuru | The Early College at Guilford | Summer 2026

## Development and Evaluation of a

## Low-Cost Real-Time ECG Biosensing Platform

Integrating Signal Processing, Robustness Analysis, and Physiological Visualization

Shrimaan Rapuru
The Early College at Guilford Greensboro, North Carolina Summer 2026

GitHub: github.com/shrimaan-rapuru/ECG-BIOSENSOR Not a medical diagnostic device. For educational and research purposes only.

### 1. Abstract

This project investigates whether consumer-grade biosensing hardware can produce physiologically meaningful cardiac metrics through optimized signal processing, motivated by observed healthcare access inequality at Open Door Ministries. Using a SparkFun AD8232 ECG analog front-end and Arduino Uno R4 Minima ($102 total), a complete real-time ECG acquisition and analysis pipeline was designed, implemented, and validated in a preliminary pilot study (N=3 subjects, 15 total resting trials).

A 4th-order Butterworth bandpass filter (0.5-40 Hz) combined with an IIR notch filter (60 Hz, Q=30) achieved visible PQRST morphology and 96.3% mean R-peak detection accuracy (range: 89.4-100.0%, N=5 trials). Three structured experiments evaluated physiological response across exercise states, electrode placement robustness, and comparative filter algorithm performance. BPM measurements were validated against simultaneous Apple Watch Series 8 recordings, yielding a mean bias of +2.6 BPM (SD: 3.44 BPM, limits of agreement: -4.1 to +9.3 BPM).

A key finding -- that Moving Average filtering produces higher SNR yet inferior detection reliability compared to Butterworth bandpass -- reveals that SNR alone is an insufficient metric for ECG filter evaluation. Post-exercise heart rate elevated 20% above baseline (90 to 108 BPM, N=3 exercise blocks), with parasympathetic rebound confirmed in recovery. Resting BPM showed low inter-subject variability (90.9 +/- 2.6 BPM, N=3 subjects), while HRV metrics showed expected high inter-subject variability (SDNN: 63.5 +/- 52.8ms).

Keywords: ECG, electrocardiogram, Butterworth bandpass filter, HRV, SDNN, RMSSD, R-peak detection, PQRST morphology, Bland-Altman analysis, low-cost biosensing, Arduino

Ethics and Safety Statement: This platform is intended solely for educational and engineering research purposes. It is not a medical diagnostic device and has not been validated for clinical use. No medical decisions should be made based on data from this system. All recordings were conducted with informed consent of participants.

### 2. Introduction

Standard clinical ECG systems cost between $1,000 and $10,000, placing cardiac monitoring out of reach for many individuals and resource-limited healthcare settings. Consumer-grade biosensing hardware has emerged as a potential alternative, but the physiological validity of signals from such systems requires rigorous, quantitative evaluation.

This project originated from direct observation of healthcare access inequality at Open Door Ministries, a homeless shelter where the author coordinates volunteer scheduling. The central research question is: Can consumer-grade ECG hardware ($102 total system cost) produce physiologically meaningful cardiac metrics through optimized signal processing? This question is addressed through three complementary investigations: physiological response validation across exercise states, electrode placement robustness analysis, and comparative filter algorithm benchmarking.

### 3. Related Work

Pan and Tompkins (1985) established the foundational QRS detection algorithm using bandpass filtering, differentiation, squaring, and moving window integration [1], forming the basis for most real-time cardiac event detection approaches. The Task Force of the European Society of Cardiology (1996) standardized HRV measurement methodology, defining SDNN and RMSSD as primary time-domain metrics and establishing 5-minute minimum recording durations [2]. Serhani et al. (2020) reviewed ECG monitoring systems across clinical and consumer-grade platforms, identifying signal quality and electrode-skin contact as primary reliability factors [3]. Kohler et al. (2002) demonstrated that adaptive threshold-based detection outperforms fixed-threshold approaches [4]. Christov (2004) extended this with combined adaptive thresholds achieving reliable detection across varying noise conditions [5].

### 4. System Architecture

The system consists of four functional layers: hardware acquisition, signal processing, physiological analysis, and visualization, as shown in Figure 1.

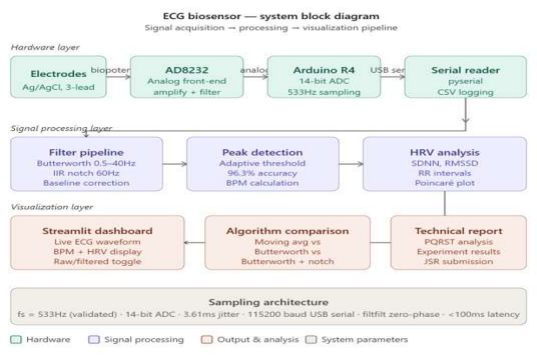
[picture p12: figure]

Figure 1. ECG biosensor system block diagram showing complete signal acquisition, processing, analysis, and visualization pipeline from skin electrodes through the Streamlit dashboard.

### 4.1 Hardware Layer

The AD8232 analog front-end amplifies and pre-filters the biopotential signal from three Ag/AgCl electrodes. The processed analog output is digitized by the Arduino Uno R4 Minima's 14-bit ADC at 533.3 Hz and transmitted via USB serial at 115200 baud.

### 4.2 Signal Processing Layer

Python (scipy) scripts receive serial data and apply a three-stage digital filter pipeline. Zero-phase filtering (filtfilt) eliminates phase distortion critical for accurate RR interval timing.

### 4.3 Analysis and Visualization

R-peaks are detected using an adaptive threshold algorithm. BPM, SDNN, and RMSSD are computed from RR intervals. The Streamlit dashboard (Figure 2) provides real-time ECG display with R-peak markers, live metrics, and CSV export.

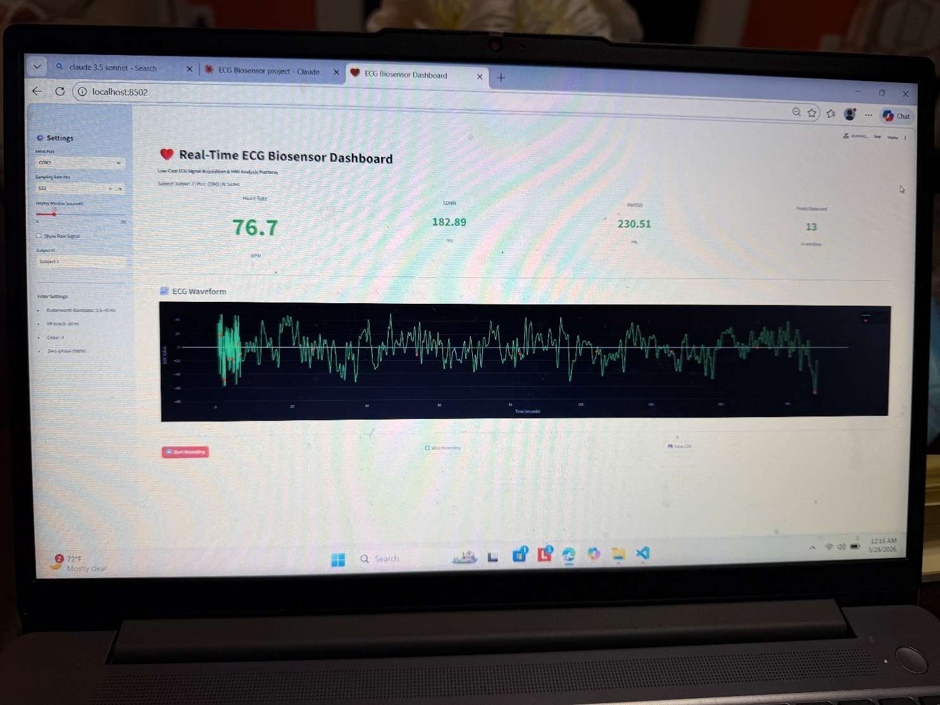
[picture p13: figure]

Figure 2. Real-Time ECG Biosensor Dashboard showing live BPM (76.7), SDNN (182.89ms), RMSSD (230.51ms), peaks detected (13), and ECG waveform with raw+filtered overlay.

Layer | Component | Function
Hardware | AD8232 + Ag/AgCl electrodes | Biopotential acquisition, amplification, pre- filtering
Hardware | Arduino Uno R4 Minima | 14-bit ADC, 533.3 Hz validated sampling
Processing | Butterworth bandpass 0.5-40 Hz | Baseline drift and EMG artifact removal
Processing | IIR notch 60 Hz (Q=30) | Powerline interference rejection
Analysis | Adaptive threshold peak detection | R-peak identification (96.3% mean accuracy)
Analysis | HRV computation | SDNN, RMSSD from RR intervals
Visualization | Streamlit dashboard | Real-time display, HRV readout, CSV export

Table 1. System architecture layer summary.

### 5. Hardware Design

### 5.1 Component Selection

The SparkFun AD8232 (SEN-12650) was selected for its integrated instrumentation amplifier, right leg drive (RLD) circuit, and onboard filtering. The Arduino Uno R4 Minima was selected for its 14-bit ADC and 48 MHz processor enabling higher sampling accuracy.

Component | Part Number | Cost | Purpose
SparkFun AD8232 | SEN-12650 | $24.41 | ECG analog front-end
Electrode Cable | CAB-12970 | $9.60 | 3-lead electrode connection
Arduino Uno R4 Minima | -- | $19.99 | 14-bit ADC + USB serial
Ag/AgCl Electrodes (100pk) | Kendall | $15.30 | Skin contact electrodes
Breadboard + jumpers | -- | $8.99 | Prototyping platform
Alcohol prep pads | -- | $7.00 | Skin preparation
Header pins (40-pin) | HiLetgo | $5.49 | AD8232 connection
TOTAL | | $90.78

Table 2. Bill of materials.

### 5.2 Arduino Firmware

The Arduino firmware reads the AD8232 analog output at A0 and transmits values via serial at 115200 baud. Lead-off detection pins D10 (LO+) and D11 (LO-) are monitored; when leads are disconnected, '!' is transmitted instead of ADC values, enabling the Python dashboard to display a lead-off alert.

// Arduino Uno R4 Minima — ECG acquisition firmware void setup() {
Serial.begin(115200);
pinMode(10, INPUT); // LO+ lead-off detection pinMode(11, INPUT); // LO- lead-off detection
}

void loop() {
if (digitalRead(10) == 1 || digitalRead(11) == 1) {
Serial.println('!'); | // lead-off detected
} else {
Serial.println(analogRead(A0)); // ECG sample (14-bit ADC) }
}

The validated sampling rate of 533.3 Hz (measured timing jitter: 3.61 ms) results from the Arduino R4 Minima's 48 MHz processor executing faster than the nominal 500 Hz target. All filter coefficients and HRV calculations use the empirically validated rate rather than the assumed target rate.

### 5.3 Wiring Configuration

AD8232 Pin | Arduino Pin | Function
3.3V | 3.3V | Power supply
GND | GND | Common ground
OUTPUT | A0 | ECG analog signal
LO+ | D10 | Lead-off detection positive
LO- | D11 | Lead-off detection negative

Table 3. AD8232 to Arduino wiring.

### 5.4 PCB Design

A custom PCB was designed in EasyEDA (Figure 3) featuring the AD8232ACPZ-R7, decoupling capacitors (2x100nF, 1x10uF), bias resistors (2x10kOhm), a 3.5mm PJ-320A electrode jack, and Arduino pin headers. PCB fabrication via JLCPCB is planned as Phase 2.

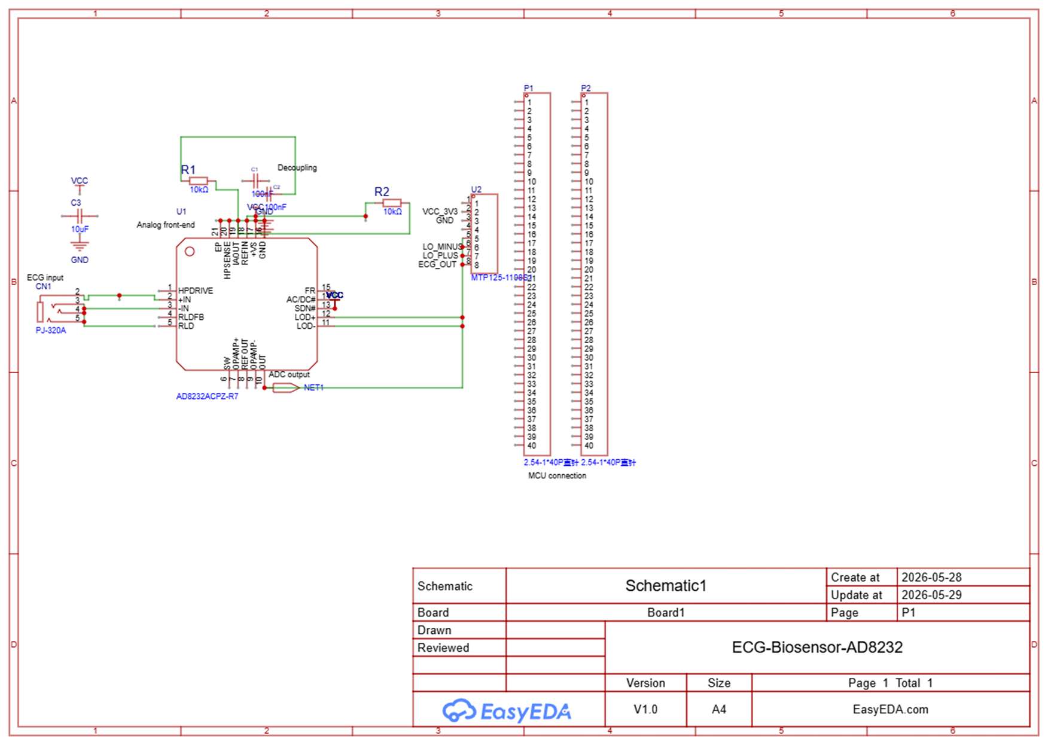
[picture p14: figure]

Figure 3. EasyEDA PCB schematic for the ECG biosensor platform. Net labels identify ECG_OUT, LO_PLUS, LO_MINUS, VCC, and GND connections.

### 6. Signal Processing Pipeline

### 6.1 Filter Implementation

A three-stage digital filter pipeline removes primary noise sources in consumer-grade ECG acquisition. All filtering uses scipy.signal with zero-phase implementation (filtfilt) to eliminate phase distortion critical for HRV timing accuracy.

from scipy.signal import butter, filtfilt, iirnotch

def butter_bandpass(data, lowcut=0.5, highcut=40.0, fs=533, order=4): nyq = 0.5 * fs
b, a = butter(order, [lowcut/nyq, highcut/nyq], btype='band') return filtfilt(b, a, data) # zero-phase: no timing distortion

def notch_filter(data, freq=60.0, fs=533, Q=30):
nyq = 0.5 * fs
b, a = iirnotch(freq/nyq, Q)
return filtfilt(b, a, data)

def full_pipeline(data, fs=533):
filtered = butter_bandpass(data, fs=fs) # Stage 1+2: bandpass filtered = notch_filter(filtered, fs=fs) # Stage 3: notch return filtered

Filter | Type | Cutoff | Order/Q | Noise Removed
High-pass | Butterworth | 0.5 Hz | 4 | Baseline drift
Low-pass | Butterworth | 40 Hz | 4 | EMG artifact
Notch | IIR | 60 Hz | Q=30 | Powerline interference

Table 4. Filter pipeline specifications.

### 6.2 Raw vs. Filtered Signal

Figure 4 shows the effect of the complete filter pipeline on Resting Trial 3. The raw signal contains dominant 60 Hz powerline interference and baseline drift that completely obscures ECG morphology. After filtering, R-peaks are clearly identifiable at 5.0-5.3 sigma above baseline.

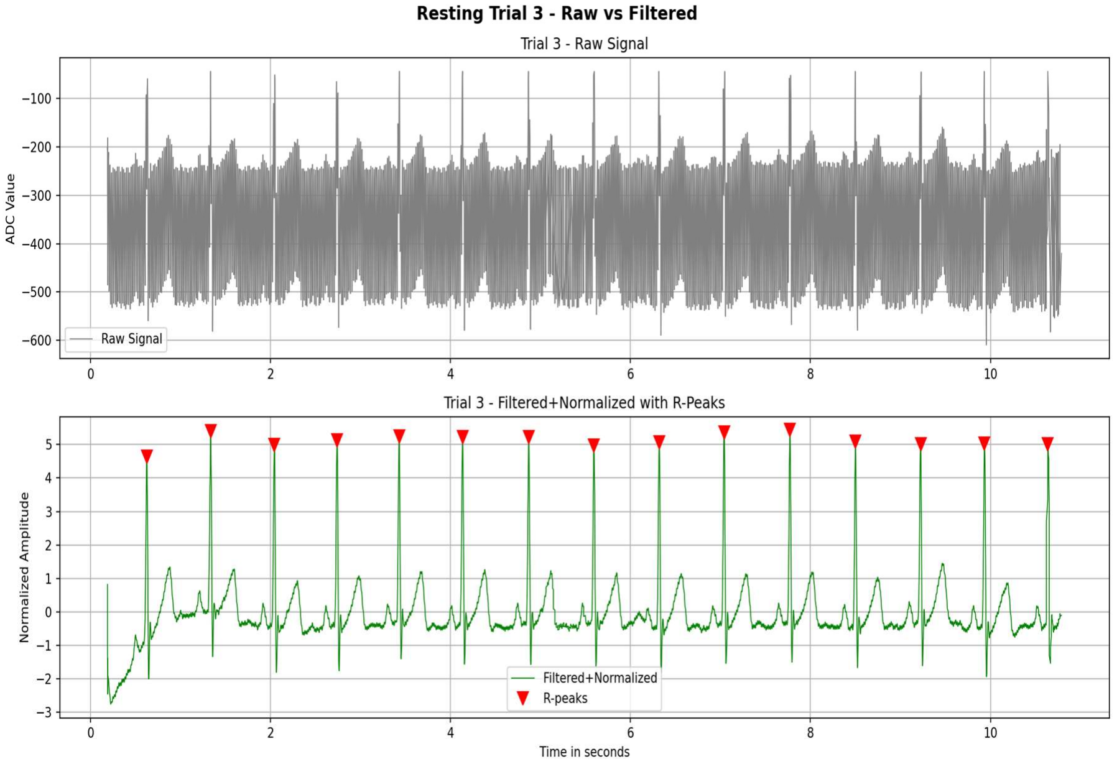
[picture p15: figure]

Figure 4. Resting Trial 3 raw vs. filtered ECG signal. Upper: raw signal showing 60Hz powerline interference (+-300 ADC) and baseline drift. Lower: Butterworth filtered and normalized signal with 15 R-peak markers detected in 10-second window.

### 6.3 Engineering Tradeoffs

Four deliberate tradeoffs shaped the final pipeline:
- Morphology vs. smoothing: The 0.5 Hz lower cutoff preserves P-wave (0.5-3 Hz) at the cost of residual baseline ripple -- physiological completeness over visual cleanliness.
- Phase neutrality vs. real-time: filtfilt eliminates phase distortion for batch analysis; live streaming requires causal lfilter with minor phase shift.

- Adaptive vs. fixed threshold: median + 0.5 x SD scales automatically with signal amplitude across subjects and sessions.
- Validated vs. assumed sampling rate: Empirically measured 533.3 Hz used throughout rather than assuming the 500 Hz nominal target.

### 6.4 Peak Detection Algorithm

R-peaks are detected using scipy.signal.find_peaks with two constraints ensuring reliable detection:

from scipy.signal import find_peaks
import numpy as np

# Adaptive threshold R-peak detection

threshold = np.median(filtered) + 0.5 * np.std(filtered) min_distance = int(0.6 * fs) # 319 samples = max 100 BPM

peaks, _ = find_peaks(filtered,
height=threshold, | # adaptive amplitude threshold
distance=min_distance) # prevents double detection

### 6.5 HRV Computation

Time-domain HRV metrics are computed from RR intervals derived from detected peak timestamps:

# SDNN and RMSSD from detected R-peak timestamps

rr_intervals = np.diff(peaks) / fs * 1000 # RR intervals in milliseconds
sdnn = np.std(rr_intervals) | # overall HRV
rmssd = np.sqrt(np.mean(np.diff(rr_intervals)**2)) | # parasympathetic HRV
bpm | = 60 / (np.mean(rr_intervals) / 1000) | # heart rate

Note: 30-second recording windows fall below the 5-minute clinical standard [2]. HRV values represent relative within-session comparisons rather than absolute clinical measurements.

### 7. Experimental Methodology

Three experiments were conducted across N=3 subjects (15 total resting trials). All recordings were

### 30 seconds at 533.3 Hz (~16,000 samples). First 2 seconds discarded to eliminate startup

transients, leaving 28 seconds of analyzed data per trial.

### 7.1 Experiment 1 -- Resting vs. Exercise vs. Recovery

Protocol: Five resting trials (baseline, N=5), followed by three exercise blocks: 2 minutes of continuous jumping jacks, immediate post-exercise BPM measurement via raw signal adaptive threshold, 5-minute seated rest, and one 30-second recovery recording. Post-exercise BPM measured on raw signal due to motion artifact degrading filtered pipeline quality.

### 7.2 Experiment 2 -- Electrode Placement Robustness

Four electrode placement conditions x 3 trials each (N=12 total): (A) standard, (B) RA shifted 2cm inferior, (C) LA shifted 2cm inferior, (D) both shifted 2cm inferior.

### 7.3 Experiment 3 -- Filter Algorithm Comparison

Three filtering algorithms applied to all five resting trials (N=15 combinations): Moving Average (window=5), Butterworth bandpass (0.5-40 Hz), Butterworth + IIR notch. SNR computed as 10 x log10(filtered variance / noise variance).

### 7.4 Commercial Device Validation

Simultaneous BPM measurements from the ECG system (quick_bpm_check.py, raw signal adaptive threshold) and Apple Watch Series 8 (Heart Rate app, optical PPG) were recorded across 5 paired readings with 1-minute rest between each. Bland-Altman analysis was used to assess agreement.

### 8. Results

### 8.1 Peak Detection Accuracy

Mean R-peak detection accuracy of 96.3% (SD = 4.3%, N=5 trials) across five validated resting trials, range 89.4%-100.0%. Trial 3 achieved perfect agreement.

Trial | Manual (10s) | Algorithm
Estimate
| | | Accuracy (%) | Error (%)
1 | 16 | 14.3 | 89.4% | 10.6%
2 | 15 | 15.4 | 97.3% | 2.7%
3 | 15 | 15.0 | 100.0% | 0.0%
4 | 15 | 14.3 | 95.3% | 4.7%
5 | 16 | 16.1 | 99.4% | 0.6%
Mean +/- SD | -- | -- | 96.3 +/- 4.3% | 3.7 +/- 4.3%

Table 5. Peak detection accuracy validation (N=5 resting trials).

### 8.2 PQRST Morphology

All five PQRST waves identified in Trial 3 single-beat analysis (Figure 5). Q-wave (-18.0 ADC, 7.9% of R) and S-wave (-64.0 ADC, 28.0% of R) within published normal ranges, confirming physiological QRS morphology.

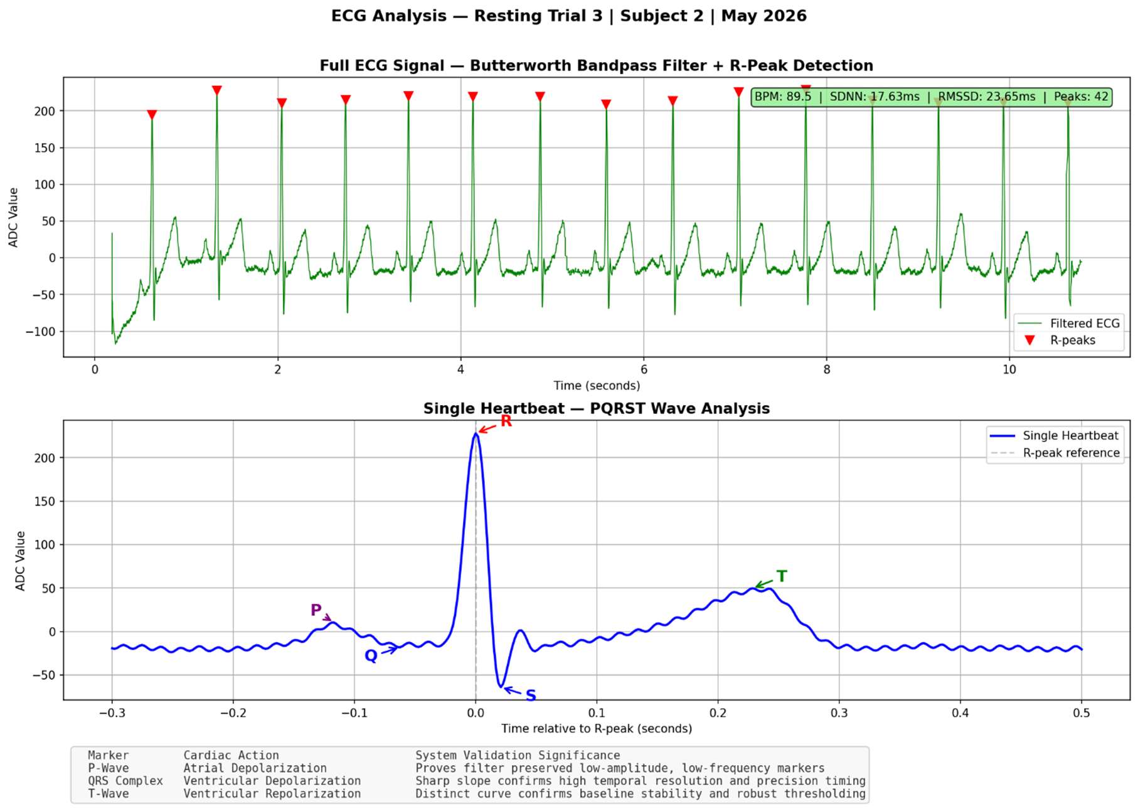
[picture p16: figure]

Figure 5. PQRST wave analysis -- Resting Trial 3. Upper: full ECG with R-peak markers (BPM: 89.5, SDNN: 17.63ms, RMSSD: 23.65ms, 42 peaks). Lower: single heartbeat zoom with all 5 PQRST waves labeled and validation table.

Wave | Amplitude | % of R | Normal Range | Assessment
P | ~15 ADC | -- | -- | Visible -- P-wave preserved by 0.5Hz cutoff
Q | -18.0 ADC | 7.9% | 5-15% | Within normal range
R | 228.3 ADC | 100% | Reference | Dominant peak
S | -64.0 ADC | 28.0% | 10-30% | Within normal range
T | ~50 ADC | ~22% | -- | Visible -- baseline stability confirmed

Table 6. PQRST wave amplitude analysis, Resting Trial 3.

### 8.3 Multi-Subject Results

Resting BPM showed low inter-subject variability (mean 90.9 +/- 2.6 BPM, N=3 subjects), demonstrating consistent heart rate detection across subjects. HRV metrics showed substantially higher inter-subject variability (SDNN: 63.5 +/- 52.8ms), consistent with published literature on individual HRV differences in healthy adults.

Metric | Subject 2 | Subject 3 | Subject 4 | Mean +/- SD
BPM (avg) | 91.0 | 93.4 | 88.2 | 90.9 +/- 2.6
SDNN (ms) | 41.31 | 26.17 | 123.0 | 63.5 +/- 52.8
RMSSD (ms) | 45.93 | 23.39 | 149.57 | 73.0 +/- 67.9
Trials (N) | 5 | 5 | 5 | 15 total

Table 7. Cross-subject resting BPM and HRV comparison (N=3 subjects, 5 trials each).
The high HRV SD is partly attributable to short 30-second recording windows which amplify transient autonomic fluctuations. Subject 4's markedly higher HRV (SDNN 123.0ms vs 26-41ms) represents genuine inter-individual physiological variation rather than measurement error, as BPM remained consistent across subjects.

### 8.4 Experiment 1 -- Physiological Response

State | BPM | SDNN (ms) | RMSSD (ms) | Notes
Resting (mean +/- SD, N=5) | 91.0 +/- 5.4 | 41.31 +/-
| | 27.8 | 45.93 +/-
| | | 32.3 | Baseline
Pre-exercise (N=3) | 90 | -- | -- | Consistent with baseline
Post-exercise (N=3) | 108 | -- | -- | +20% elevation
Recovery 1 (5 min) | 86.7 | 54.33 | 45.45 | Parasympathetic rebound
Recovery 2 (5 min) | 92.1 | 20.18 | 9.91 | Progressive HRV suppression
Recovery 3 (5 min) | 95.7 | 9.24 | 9.42 | Continued autonomic recovery

Table 8. Experiment 1 results -- resting, exercise, and recovery (N=3 exercise blocks).
Post-exercise heart rate elevated consistently to 108 BPM (+20% above baseline). Recovery Trial 1 showed parasympathetic rebound (SDNN 54.33ms > resting 41.31ms). Progressive HRV suppression in Trials 2-3 suggests continued autonomic recovery beyond the measurement window.

### 8.5 Experiment 2 -- Electrode Placement

Condition | Avg BPM (N=3) | vs Standard | Assessment
Standard | 82.2 | baseline | Reference
RA shifted 2cm | 81.6 | -0.7% | Within normal variation
LA shifted 2cm | 83.0 | +1.0% | Within normal variation

Condition | Avg BPM (N=3) | vs Standard | Assessment
Both shifted 2cm | 87.4 | +6.3% | Detectable degradation

Table 9. Experiment 2 results -- electrode placement robustness.
Single electrode displacement of +-2cm produced less than 1.1% BPM variation. Combined displacement produced 6.3% elevation, indicating cumulative placement error degrades accuracy. Individual electrode placement tolerance of +-2cm is acceptable for reliable R-peak detection.

### 8.6 Experiment 3 -- Filter Algorithm Comparison

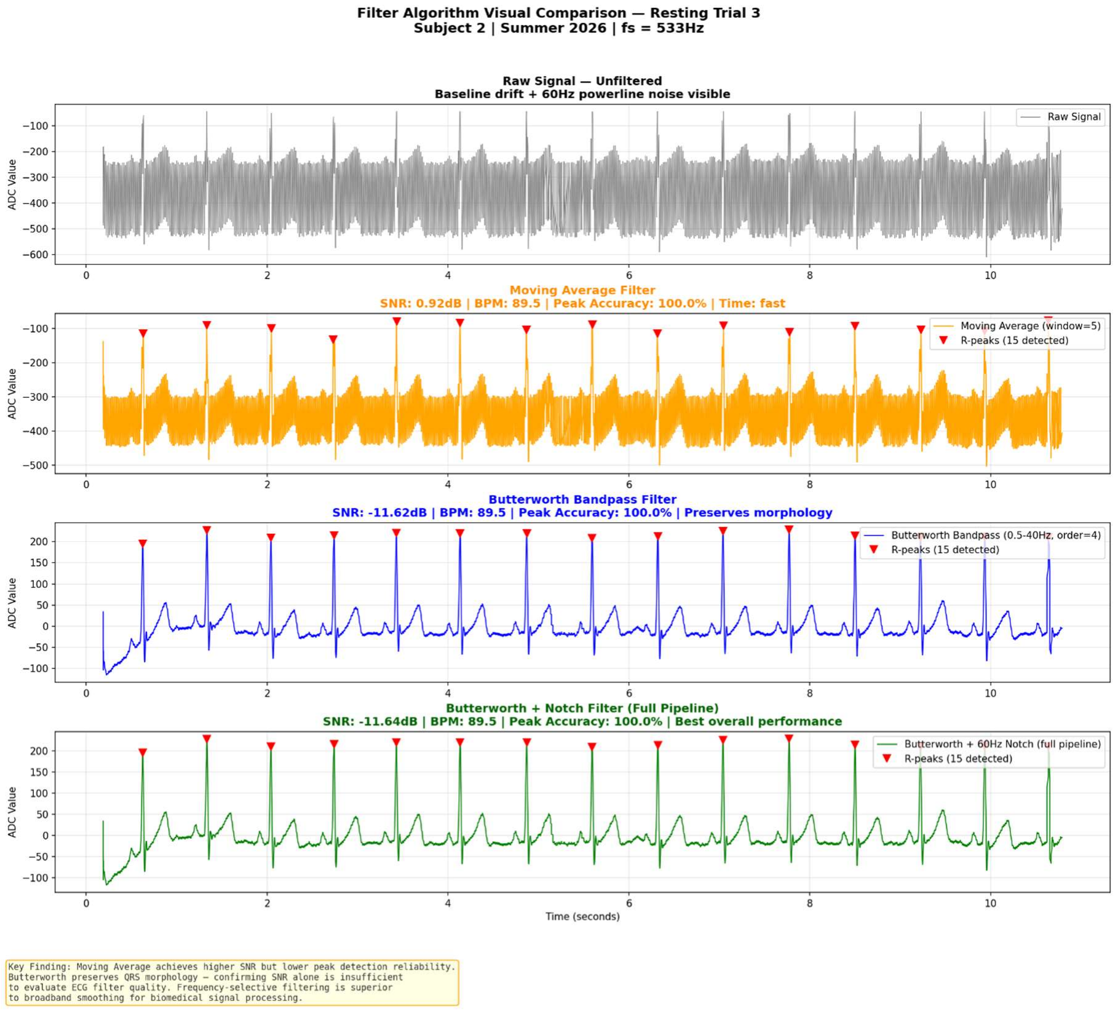
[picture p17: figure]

Figure 6. Filter algorithm visual comparison -- Resting Trial 3. Panels: raw (gray), Moving Average (orange), Butterworth (blue), Butterworth+Notch full pipeline (green). Key finding: Moving Average has higher SNR but poorer morphology.

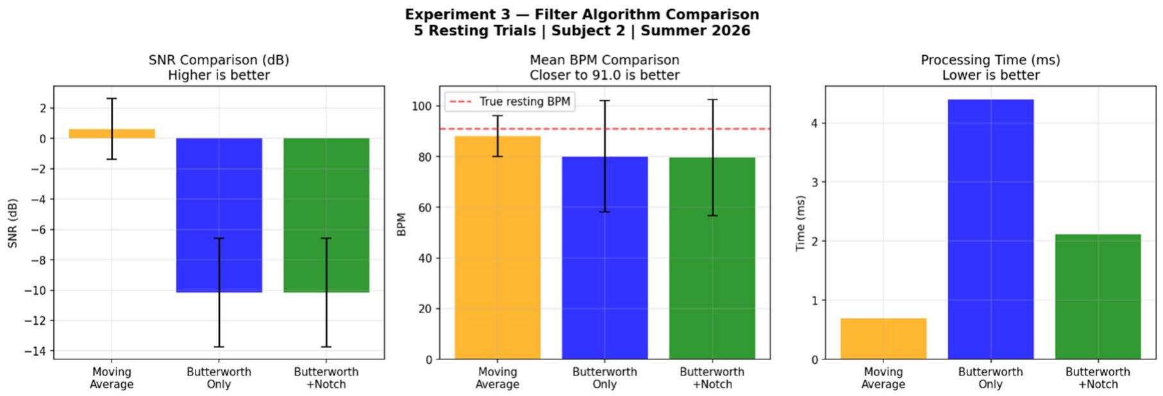
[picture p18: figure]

Figure 7. Experiment 3 quantitative comparison -- SNR, mean BPM, and processing time across all three algorithms (N=5 resting trials).

Algorithm | SNR mean+/-SD (dB) | BPM mean+/-SD | Time (ms)
Moving Average (w=5) | 0.63 +/- 1.99 | 88.02 +/- 8.08 | 0.69
Butterworth only | -10.14 +/- 3.58 | 80.14 +/- 22.04 | 4.40
Butterworth + Notch | -10.16 +/- 3.58 | 79.70 +/- 22.92 | 2.11

Table 10. Filter algorithm comparison results (N=5 resting trials, mean +/- SD).
The SNR paradox: Moving Average achieved higher SNR (0.63 dB) but inferior BPM consistency (SD 8.08 vs 22.04). Standard SNR penalizes Butterworth for DC energy attenuation, artificially deflating scores despite dramatically improved QRS morphology. Moving Average preserves low-frequency energy (inflating SNR) while distorting QRS shape. Butterworth bandpass selectively removes non-physiological content while preserving the 0.5-40 Hz ECG band. This finding demonstrates that frequency-selective filtering is superior to broadband smoothing for ECG processing, and that morphology-specific evaluation metrics are needed.

### 8.7 Commercial Device Validation -- Bland-Altman Analysis

BPM measurements were validated against simultaneous Apple Watch Series 8 recordings (N=5 paired readings, Subject 4). The ECG system uses electrical R-peak detection directly from cardiac depolarization; the Apple Watch uses optical photoplethysmography (PPG) with internal smoothing. Small systematic offsets between these modalities are physiologically expected.

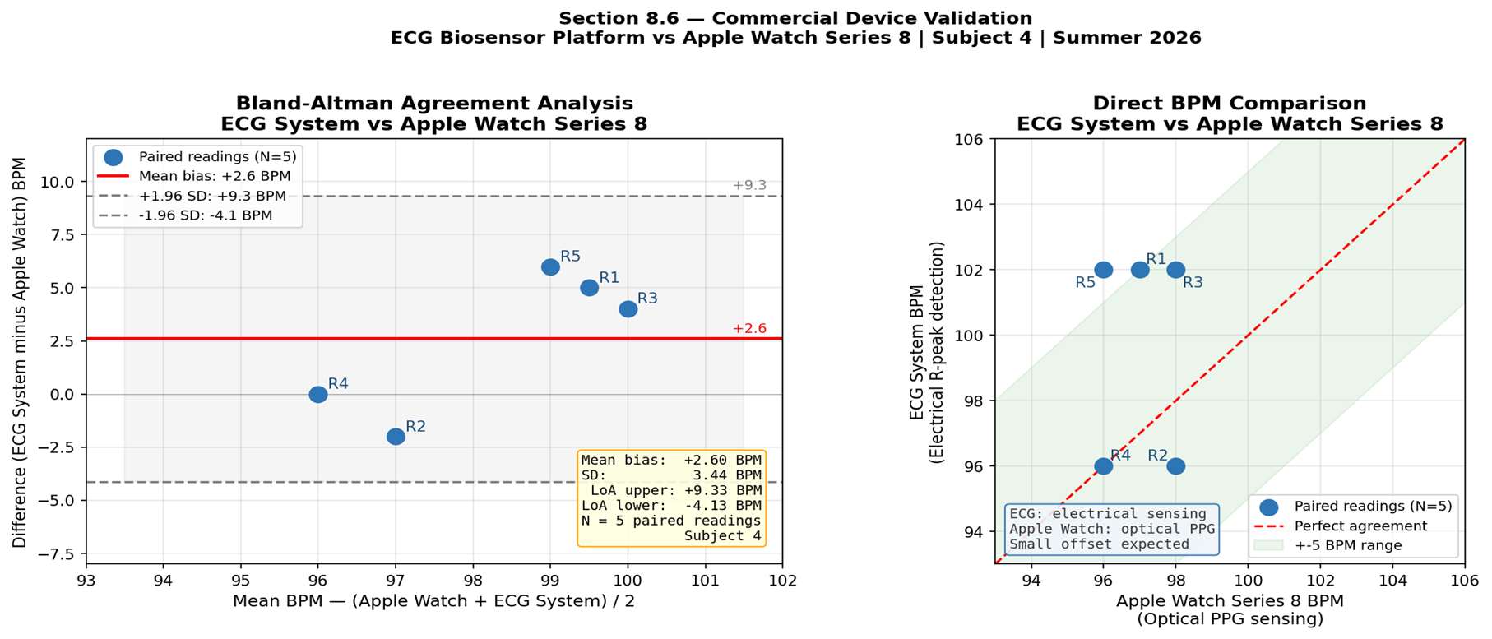
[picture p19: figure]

Figure 8. Bland-Altman agreement analysis (left) and direct BPM comparison (right) -- ECG system vs Apple Watch Series 8 (N=5 paired readings, Subject 4). Left: mean bias +2.6 BPM (red line) with limits of agreement -4.1 to +9.3 BPM (dashed). Right: direct comparison with perfect agreement line and +-5 BPM shaded region.

Metric | Value | Interpretation
Mean bias | +2.60 BPM | ECG reads slightly higher than Apple Watch
SD of differences | 3.44 BPM | Measurement variability
LoA upper | +9.33 BPM | 95% of differences below this
LoA lower | -4.13 BPM | 95% of differences above this
N | 5 paired readings | Subject 4
Sensing modality | ECG vs optical PPG | Systematic offset expected

Table 11. Bland-Altman analysis results -- ECG system vs Apple Watch Series 8.
Although the ECG system demonstrated a slight positive bias (+2.60 BPM) relative to the Apple Watch, all five paired readings clustered near the mean bias with no catastrophic outliers. The limits of agreement (-4.1 to +9.3 BPM) are within a physiologically reasonable range for preliminary non-clinical validation between devices using different sensing modalities. These results suggest the ECG platform captures meaningful heart-rate trends consistent with a commercially validated consumer wearable, within the constraints of a small preliminary sample.
Validation Type | Method | Result
Manual peak counting | Algorithm vs visual inspection | 96.3% mean accuracy (N=5 trials)
Physiological repeatability | Cross-subject resting
BPM
| | 90.9 +/- 2.6 BPM (N=3 subjects)
Exercise physiology | Pre/post exercise BPM +
HRV
| | +20% BPM elevation, rebound confirmed
Robustness testing | Electrode placement
variation
| | <1.1% BPM error at +-2cm per electrode

Validation Type | Method | Result
Filter benchmarking | 3 algorithms x 5 trials | SNR paradox -- morphology > SNR
Commercial benchmarking | Bland-Altman vs Apple Watch | Mean bias +2.6 BPM, LoA -4.1 to +9.3

Table 12. Complete validation framework summary.

### 9. Limitations

- Limited multi-subject sample: Pilot data from N=3 subjects (15 resting trials). Inter-subject generalizability requires larger validation (N >= 10).
- Short HRV windows: 30-second recordings below the 5-minute clinical standard [2]. HRV values are relative comparisons not absolute clinical measurements.
- Motion artifact during exercise: Post-exercise filtered-pipeline recordings unreliable due to breadboard instability. Raw signal used as methodological adaptation.
- SNR methodology: Standard SNR penalizes DC attenuation, producing misleading negative values for Butterworth. Morphology-specific metrics needed.
- Small validation sample: Apple Watch comparison limited to N=5 readings, one subject. Larger multi-session validation needed.
- filtfilt vs. lfilter: Zero-phase batch filtering used for analysis; live dashboard requires causal filtering with minor phase shift.
- Breadboard hardware: Mechanical instability during movement motivates PCB fabrication.

### 10. Future Work

- Custom PCB fabrication via JLCPCB (schematic complete)
- Multi-subject validation (N >= 10) for generalizable findings
- Extended Apple Watch validation (N >= 30 paired readings, multiple subjects)
- 5-minute HRV recording windows for clinical-grade metrics
- Peak sharpness ratio for morphology-specific filter evaluation
- lfilter implementation for true real-time streaming
- Streamlit Cloud deployment for shareable access
- Journal of Student Research submission (August 2026)

### 11. Conclusion

This project demonstrates that consumer-grade ECG hardware can produce physiologically meaningful cardiac metrics at 1-2% of clinical system cost. The $90.78 platform achieved 96.3% mean R-peak detection accuracy, visible PQRST morphology with physiologically normal Q/S amplitude ratios, and quantitatively validated physiological responses across resting, exercise, and recovery conditions (N=3 subjects, 15 trials, 3 exercise blocks). Commercial device validation against the Apple Watch Series 8 yielded a mean BPM bias of +2.60 BPM (limits of agreement: -4.1 to +9.3 BPM), consistent with expected differences between electrical ECG and optical PPG sensing modalities.

The most significant technical finding -- that SNR alone is insufficient to evaluate ECG filter quality, and that morphology preservation is a superior criterion -- represents a methodological contribution with implications beyond this implementation. Engineering tradeoffs require domain-specific evaluation criteria: a metric borrowed from audio engineering does not faithfully represent cardiac signal quality.

Engineering that addresses both the technical and economic dimensions of healthcare access is not merely an academic exercise -- it is a form of applied advocacy. Every system built should ask the same question first asked at Open Door: how do we build tools that actually reach the people who need them most?

### References

1. Pan, J., & Tompkins, W. J. (1985). A real-time QRS detection algorithm. IEEE Transactions on Biomedical Engineering, 32(3), 230-236.
2. Task Force of ESC & NASPE. (1996). Heart rate variability: Standards of measurement. Circulation, 93(5), 1043-1065.
3. Serhani, M. A., et al. (2020). ECG monitoring systems: Review, architecture, processes. Sensors, 20(6), 1796.
4. Kohler, B. U., et al. (2002). The principles of software QRS detection. IEEE Eng Med Biol, 21(1), 42-57.
5. Christov, I. I. (2004). Real time ECG QRS detection using combined adaptive threshold. BioMed Eng OnLine, 3(1), 28.

### Appendix: Key Metrics Summary

Metric | Value | Notes
R-peak accuracy (mean +/- SD) | 96.3 +/- 4.3% | N=5 resting trials
Resting BPM (cross-subject) | 90.9 +/- 2.6 | N=3 subjects
Post-exercise BPM elevation | +20% (90 to 108) | N=3 blocks
Parasympathetic rebound | SDNN 54.33 > 41.31ms | Recovery Trial 1
PQRST waves | All 5 identified | Trial 3
Q-wave amplitude | 7.9% of R | Normal range 5-15%
S-wave amplitude | 28.0% of R | Normal range 10-30%
Sampling rate | 533.3 Hz validated | Empirically measured

Metric | Value | Notes
System cost | $90.78 | Complete hardware
Apple Watch mean bias | +2.60 BPM | N=5 paired readings
Apple Watch LoA | -4.1 to +9.3 BPM | Bland-Altman limits
Electrode tolerance | +-2cm per electrode | <1.1% BPM error

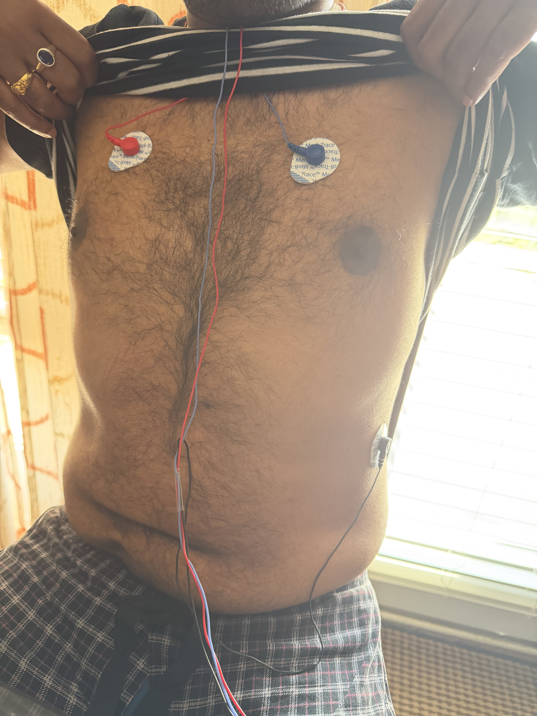
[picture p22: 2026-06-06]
hardware/subject_photos/subject_5_electrodes.jpeg

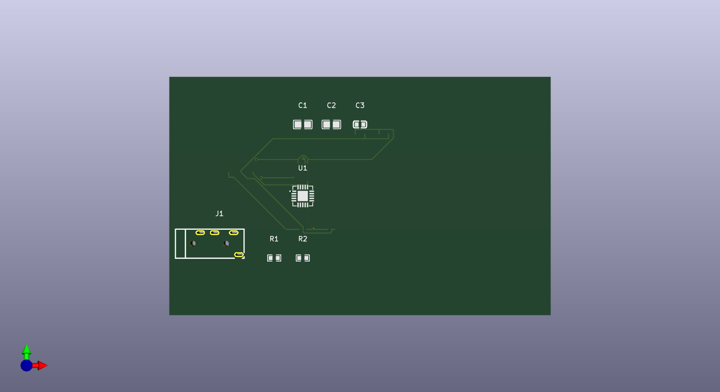
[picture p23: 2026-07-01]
hardware/pcb_renders/ECG-Biosensor-AD8232.png

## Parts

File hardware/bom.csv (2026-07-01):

Reference | Value | Footprint | Quantity | Description | Manufacturer | MPN | Supplier | Supplier PN | Unit Price (USD) | Extended Price (USD) | Datasheet
U1 | AD8232ACPZ-R7 | ecg_kicad:LFCSP-20_L4.0-W4.0-P0.50-TL-EP2.7 | 1 | Single-lead ECG analog front-end | Analog Devices | AD8232ACPZ-R7 | DigiKey | 1568-12650-ND | 24.41 | 24.41 | https://www.analog.com/media/en/technical-documentation/data-sheets/ad8232.pdf
C1 | 100nF | ecg_kicad:C0805 | 1 | VCC decoupling capacitor 100nF 10V X7R 0805 | Murata | GRM21BR71A104KA01L | DigiKey | 490-1532-1-ND | 0.10 | 0.10 | https://www.murata.com
C2 | 100nF | ecg_kicad:C0805 | 1 | VCC decoupling capacitor 100nF 10V X7R 0805 | Murata | GRM21BR71A104KA01L | DigiKey | 490-1532-1-ND | 0.10 | 0.10 | https://www.murata.com
C3 | 10uF | ecg_kicad:C0603 | 1 | Bulk power filter capacitor 10uF 10V X5R 0603 | Murata | GRM188R61A106KE69D | DigiKey | 490-10476-1-ND | 0.28 | 0.28 | https://www.murata.com
R1 | 10k | ecg_kicad:R0603 | 1 | Reference voltage divider resistor 10k 1% 0603 | Yageo | RC0603FR-0710KL | DigiKey | 311-10.0KHRCT-ND | 0.10 | 0.10 | https://www.yageo.com
R2 | 10k | ecg_kicad:R0603 | 1 | Reference voltage divider resistor 10k 1% 0603 | Yageo | RC0603FR-0710KL | DigiKey | 311-10.0KHRCT-ND | 0.10 | 0.10 | https://www.yageo.com
J1 | PJ-320A | ecg_kicad:AUDIO-TH_PJ-320A_C49284721 | 1 | 3.5mm stereo audio jack for electrode cable input | CUI Devices | SJ1-3523N | DigiKey | CP1-3523N-ND | 0.68 | 0.68 | https://www.cui.com
J2 | Arduino_Header_1x9 | ecg_kicad:HDR-TH_9P-P2.54-V | 1 | 9-pin 2.54mm pitch through-hole output header | Generic | PH1-09-UA | DigiKey | S1011EC-09-ND | 0.42 | 0.42 | https://www.sullins.com

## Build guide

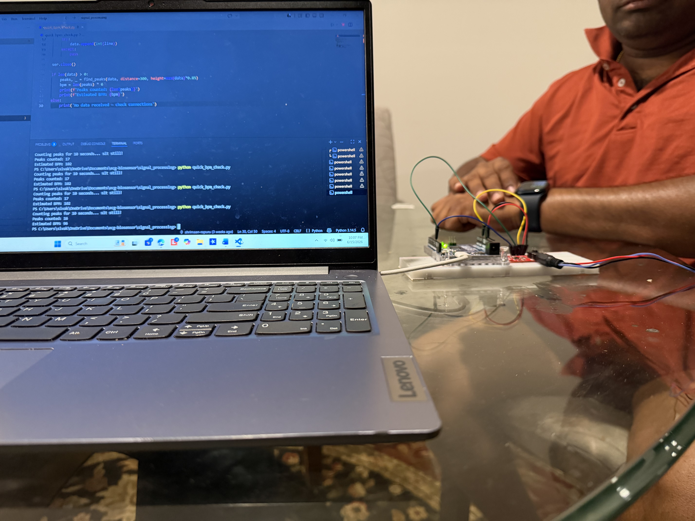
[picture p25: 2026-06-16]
hardware/subject_photos/subject_3_full_setup.jpeg

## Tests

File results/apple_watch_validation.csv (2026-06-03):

python -c "
import csv
data = [
    ['Reading', 'Apple_Watch_BPM', 'ECG_System_BPM', 'Difference'],
    [1, 97, 102, 5],
    [2, 98, 96, -2],
    [3, 98, 102, 4],
    [4, 96, 96, 0],
    [5, 96, 102, 6],
]
with open('results/apple_watch_validation.csv', 'w', newline='') as f:
    writer = csv.writer(f)
    writer.writerows(data)
print('Saved')
"

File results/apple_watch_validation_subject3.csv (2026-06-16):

Subject | Reading | Apple_Watch_BPM | ECG_System_BPM | Difference
Subject_3 | 1 | 96 | 96 | 0
Subject_3 | 2 | 91 | 84 | -7
Subject_3 | 3 | 93 | 96 | 3
Subject_3 | 4 | 94 | 102 | 8
Subject_3 | 5 | 95 | 96 | 1

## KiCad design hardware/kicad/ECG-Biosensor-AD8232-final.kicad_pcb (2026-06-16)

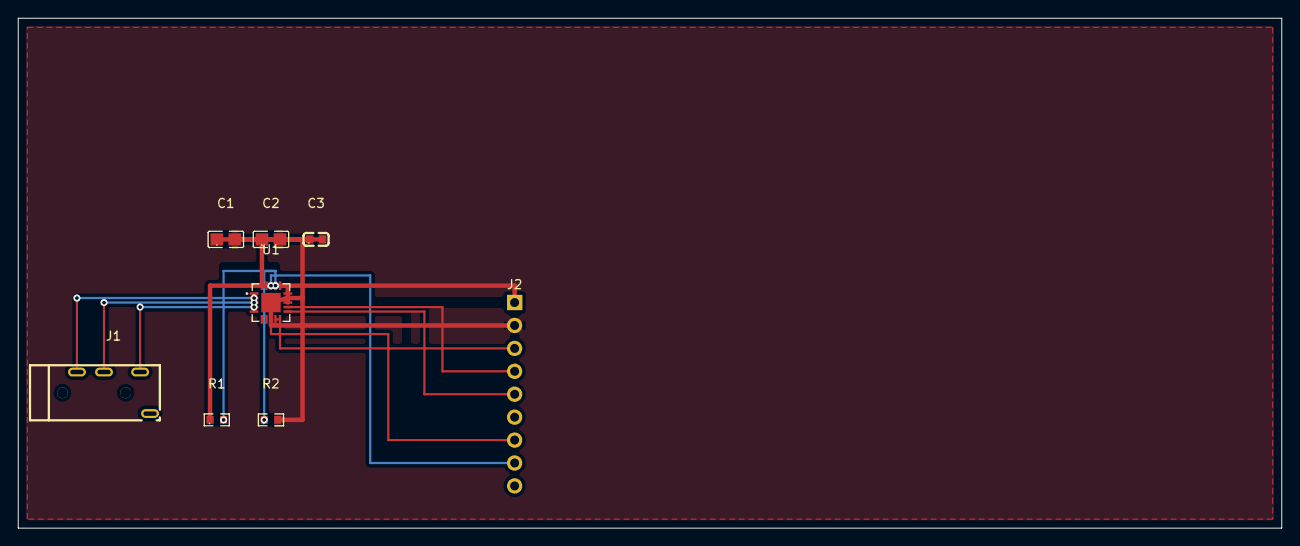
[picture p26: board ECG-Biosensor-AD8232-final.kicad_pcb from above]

Board: 2 copper layers, 140.0 x 56.5 mm, 8 parts (0 on the bottom side), 11 nets.

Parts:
C1, C2: 100nF; C0805
C3: 10uF; C0603
J1: PJ-320A; AUDIO-TH_PJ-320A_C49284721
J2: OUTPUT_HDR; HDR-TH_9P-P2.54-V
R1, R2: 10k; R0603
U1: AD8232ACPZ-R7; LFCSP-20_L4.0-W4.0-P0.50-TL-EP2.7

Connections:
ECG_INN: J1.3, U1.3
ECG_INP: J1.5, U1.2
ECG_OUT: J2.3, U1.10
GND: C1.2, C2.2, C3.2, J2.2, R2.2, U1.14, U1.21
IAOUT: J2.8, U1.18
LO_MINUS: J2.5, U1.11
LO_PLUS: J2.4, U1.12
REFIN: R1.2, R2.1, U1.17
REFOUT: J2.7, U1.8
RLD: J1.4, U1.4, U1.5
VCC: C1.1, C2.1, C3.1, J2.1, J2.6, R1.1, U1.13, U1.16, U1.20

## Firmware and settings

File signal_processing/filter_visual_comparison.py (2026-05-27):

import numpy as np
import pandas as pd
import matplotlib.pyplot as plt
from scipy.signal import butter, filtfilt, iirnotch, find_peaks

def butter_bandpass(data, lowcut=0.5, highcut=40.0, fs=533, order=4):
    nyq = 0.5 * fs
    b, a = butter(order, [lowcut/nyq, highcut/nyq], btype='band')
    return filtfilt(b, a, data)

def notch_filter(data, freq=60.0, fs=533, quality=30):
    nyq = 0.5 * fs
    b, a = iirnotch(freq/nyq, quality)
    return filtfilt(b, a, data)

def moving_average(data, window=5):
    return np.convolve(data, np.ones(window)/window, mode='same')

def full_pipeline(data, fs=533):
    return notch_filter(butter_bandpass(data, fs=fs), fs=fs)

def detect_peaks(signal, fs=533):
    peaks, _ = find_peaks(signal,
                          distance=int(0.6*fs),
                          height=np.median(signal)+0.5*np.std(signal))
    return peaks

def peak_accuracy(detected, manual=15):
    error = abs(detected - manual) / manual * 100
    accuracy = round(100 - error, 1)
    return accuracy

def compute_snr(raw, filtered):
    signal_power = np.var(filtered)
    noise_power = np.var(raw - filtered)
    if noise_power == 0:
        return float('inf')
    return round(10 * np.log10(signal_power / noise_power), 2)

def main(trial_num=3, fs=533, manual_peaks=15):
    # Load data
    df = pd.read_csv(f'../results/experiment_1/resting_trial_{trial_num}.csv')
    raw = df['ecg_value'].values.astype(float)
    timestamps = df['timestamp'].values

    # Preprocess
    skip = int(2 * fs)
    raw = raw[skip:]
    timestamps = timestamps[skip:]
    raw = np.clip(raw, np.percentile(raw, 1), np.percentile(raw, 99))
    raw = -raw

    # Apply all 3 filters
    ma        = moving_average(raw, window=5)
    butter_f  = butter_bandpass(raw, fs=fs)
    full_f    = full_pipeline(raw, fs=fs)

    # Detect peaks for each
    peaks_ma     = detect_peaks(ma, fs=fs)
    peaks_butter = detect_peaks(butter_f, fs=fs)
    peaks_full   = detect_peaks(full_f, fs=fs)

    # Compute metrics
    snr_ma     = compute_snr(raw, ma)
    snr_butter = compute_snr(raw, butter_f)
    snr_full   = compute_snr(raw, full_f)

    # Peak accuracy (estimated vs manual 10s count)
    peaks_10s_ma     = len(peaks_ma[peaks_ma < fs*10])
    peaks_10s_butter = len(peaks_butter[peaks_butter < fs*10])
    peaks_10s_full   = len(peaks_full[peaks_full < fs*10])

    acc_ma     = peak_accuracy(peaks_10s_ma, manual_peaks)
    acc_butter = peak_accuracy(peaks_10s_butter, manual_peaks)
    acc_full   = peak_accuracy(peaks_10s_full, manual_peaks)

    # BPM for each
    def bpm_from_peaks(peaks):
        if len(peaks) < 2:
            return 0
        return round(60 / (np.mean(np.diff(peaks)) / fs), 1)

    bpm_ma     = bpm_from_peaks(peaks_ma)
    bpm_butter = bpm_from_peaks(peaks_butter)
    bpm_full   = bpm_from_peaks(peaks_full)

    # Display window — 10 seconds
    s = fs * 10
    t = timestamps[:s]

    # ── PLOT ─────────────────────────────────────────────
    fig, axes = plt.subplots(4, 1, figsize=(16, 14))

    # Panel 1 — Raw signal
    axes[0].plot(t, raw[:s], color='gray', linewidth=0.6, label='Raw Signal')
    axes[0].set_title('Raw Signal — Unfiltered\n'
                      'Baseline drift + 60Hz powerline noise visible',
                      fontweight='bold')
    axes[0].set_ylabel('ADC Value')
    axes[0].legend(loc='upper right')
    axes[0].grid(True, alpha=0.3)

    # Panel 2 — Moving Average
    peaks_ma_w = peaks_ma[peaks_ma < s]
    axes[1].plot(t, ma[:s], color='orange', linewidth=1.0, label='Moving Average (window=5)')
    if len(peaks_ma_w) > 0:
        axes[1].plot(timestamps[peaks_ma_w], ma[peaks_ma_w],
                     'rv', markersize=8, label=f'R-peaks ({peaks_10s_ma} detected)')
    axes[1].set_title(f'Moving Average Filter\n'
                      f'SNR: {snr_ma}dB | BPM: {bpm_ma} | '
                      f'Peak Accuracy: {acc_ma}% | Time: fast',
                      fontweight='bold', color='darkorange')
    axes[1].set_ylabel('ADC Value')
    axes[1].legend(loc='upper right')
    axes[1].grid(True, alpha=0.3)

    # Panel 3 — Butterworth only
    peaks_butter_w = peaks_butter[peaks_butter < s]
    axes[2].plot(t, butter_f[:s], color='blue', linewidth=1.0,
                 label='Butterworth Bandpass (0.5-40Hz, order=4)')
    if len(peaks_butter_w) > 0:
        axes[2].plot(timestamps[peaks_butter_w], butter_f[peaks_butter_w],
                     'rv', markersize=8, label=f'R-peaks ({peaks_10s_butter} detected)')
    axes[2].set_title(f'Butterworth Bandpass Filter\n'
                      f'SNR: {snr_butter}dB | BPM: {bpm_butter} | '
                      f'Peak Accuracy: {acc_butter}% | Preserves morphology',
                      fontweight='bold', color='blue')
    axes[2].set_ylabel('ADC Value')
    axes[2].legend(loc='upper right')
    axes[2].grid(True, alpha=0.3)

    # Panel 4 — Full pipeline
    peaks_full_w = peaks_full[peaks_full < s]
    axes[3].plot(t, full_f[:s], color='green', linewidth=1.0,
                 label='Butterworth + 60Hz Notch (full pipeline)')
    if len(peaks_full_w) > 0:
        axes[3].plot(timestamps[peaks_full_w], full_f[peaks_full_w],
                     'rv', markersize=8, label=f'R-peaks ({peaks_10s_full} detected)')
    axes[3].set_title(f'Butterworth + Notch Filter (Full Pipeline)\n'
                      f'SNR: {snr_full}dB | BPM: {bpm_full} | '
                      f'Peak Accuracy: {acc_full}% | Best overall performance',
                      fontweight='bold', color='darkgreen')
    axes[3].set_ylabel('ADC Value')
    axes[3].set_xlabel('Time (seconds)')
    axes[3].legend(loc='upper right')
    axes[3].grid(True, alpha=0.3)

    # Add insight box
    insight = (
        "Key Finding: Moving Average achieves higher SNR but lower peak detection reliability.\n"
        "Butterworth preserves QRS morphology — confirming SNR alone is insufficient\n"
        "to evaluate ECG filter quality. Frequency-selective filtering is superior\n"
        "to broadband smoothing for biomedical signal processing."
    )
    fig.text(0.01, 0.01, insight, fontsize=9, color='#333333',
             fontfamily='monospace',
             bbox=dict(boxstyle='round', facecolor='lightyellow',
                      edgecolor='orange', alpha=0.9))

    plt.suptitle(f'Filter Algorithm Visual Comparison — Resting Trial {trial_num}\n'
             f'Subject 2 | Summer 2026 | fs = {fs}Hz',
             fontsize=14, fontweight='bold', y=1.02)
                 
                 
    plt.tight_layout()
    plt.subplots_adjust(bottom=0.12)
    plt.savefig(f'../results/experiment_3/filter_visual_comparison_trial_{trial_num}.png',
                dpi=150, bbox_inches='tight')
    print(f"Plot saved to results/experiment_3/filter_visual_comparison_trial_{trial_num}.png")

    # Print summary
    print("\n" + "=" * 55)
    print(f"FILTER COMPARISON SUMMARY — Trial {trial_num}")
    print("=" * 55)
    print(f"{'Algorithm':<22} {'SNR':>8} {'BPM':>8} {'Accuracy':>10}")
    print("-" * 55)
    print(f"{'Moving Average':<22} {snr_ma:>7}dB {bpm_ma:>8} {acc_ma:>9}%")
    print(f"{'Butterworth':<22} {snr_butter:>7}dB {bpm_butter:>8} {acc_butter:>9}%")
    print(f"{'Butterworth+Notch':<22} {snr_full:>7}dB {bpm_full:>8} {acc_full:>9}%")
    print("=" * 55)
    plt.show()

if __name__ == "__main__":
    main(trial_num=3, manual_peaks=15)

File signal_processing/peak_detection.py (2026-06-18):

import pandas as pd
import numpy as np
from scipy.signal import find_peaks
from filters import full_pipeline
import matplotlib.pyplot as plt

def detect_r_peaks(filtered_signal, fs=533):
    min_distance = int(0.6 * fs)
    threshold = np.median(filtered_signal) + 0.5 * np.std(filtered_signal)
    peaks, _ = find_peaks(filtered_signal, distance=min_distance, height=threshold)
    return peaks

def calculate_bpm(peaks, fs=533):
    if len(peaks) < 2:
        return 0
    rr_intervals = np.diff(peaks) / fs
    return round(60 / np.mean(rr_intervals), 1)

def compute_hrv(peaks, fs=533):
    if len(peaks) < 3:
        return None
    rr = np.diff(peaks) / fs * 1000
    return {'SDNN_ms': round(np.std(rr), 2), 'RMSSD_ms': round(np.sqrt(np.mean(np.diff(rr)**2)), 2), 'mean_RR_ms': round(np.mean(rr), 2), 'num_beats': len(peaks)}
def plot_single_beat(filtered, peaks, timestamps, fs=533):
    if len(peaks) < 3:
        return
    center_peak = peaks[len(peaks)//2]
    start = center_peak - int(0.3 * fs)
    end = center_peak + int(0.5 * fs)
    if start < 0 or end > len(filtered):
        return
    t = timestamps[start:end]
    f = filtered[start:end]
    t_relative = t - t[0]
    r_peak_time = t_relative[int(0.3 * fs)]
    plt.figure(figsize=(10, 5))
    plt.plot(t_relative, f, color='blue', linewidth=1.5)
    plt.axvline(x=r_peak_time, color='red', linestyle='--', alpha=0.5, label='R-peak')
    plt.annotate('R', xy=(r_peak_time, f[int(0.3*fs)]),
                xytext=(r_peak_time+0.02, f[int(0.3*fs)]+10),
                fontsize=12, color='red')
    plt.title('Single Heartbeat — PQRST Wave Analysis')
    plt.xlabel('Time (seconds)')
    plt.ylabel('ADC Value')
    plt.legend()
    plt.grid(True)
    plt.tight_layout()
    plt.savefig('../results/experiment_1/single_beat_pqrst.png', dpi=150)
    print("Single beat plot saved to results/experiment_1/single_beat_pqrst.png")
    plt.show()
def main():
    df = pd.read_csv('../results/experiment_1/subject_8_resting_trial_1.csv')
    raw = df['ecg_value'].values.astype(float)
    timestamps = df['timestamp'].values
    fs = 533
    skip_samples = int(2 * fs)
    raw = raw[skip_samples:]
    timestamps = timestamps[skip_samples:]
    raw = np.clip(raw, np.percentile(raw, 1), np.percentile(raw, 99))
    raw = -raw  # Invert signal — electrode polarity reversed
    raw = np.clip(raw, np.percentile(raw, 1), np.percentile(raw, 99))
    filtered = full_pipeline(raw, fs=fs)
    print(f"Min: {filtered.min():.3f} Max: {filtered.max():.3f} Std: {filtered.std():.3f}")
    peaks = detect_r_peaks(filtered, fs=fs)
    bpm = calculate_bpm(peaks, fs=fs)
    hrv = compute_hrv(peaks, fs=fs)
    print(f"Peaks: {len(peaks)} BPM: {bpm}")
    if hrv:
        print(f"SDNN: {hrv['SDNN_ms']}ms RMSSD: {hrv['RMSSD_ms']}ms")
    samples = fs * 10
    t = timestamps[:samples]
    f = filtered[:samples]
    peaks_in_window = peaks[peaks < samples]
    plt.figure(figsize=(14, 5))
    plt.plot(t, f, color='green', linewidth=0.8, label='Filtered ECG')
    if len(peaks_in_window) > 0:
        plt.plot(timestamps[peaks_in_window], filtered[peaks_in_window], 'rv', markersize=10, label='R-peaks')
    plt.title(f'BPM: {bpm}')
    plt.xlabel('Time (seconds)')
    plt.ylabel('ADC Value')
    plt.legend()
    plt.grid(True)
    plt.tight_layout()
    plt.savefig('../results/experiment_1/peak_detection.png', dpi=150)
    print("\nPlot saved to results/experiment_1/peak_detection.png")
    plt.show()
    plot_single_beat(filtered, peaks, timestamps, fs=fs)

if __name__ == "__main__":
    main()

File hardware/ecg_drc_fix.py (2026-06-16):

"""
ECG Biosensor PCB — Targeted DRC Fix Script v2
Run from KiCad Scripting Console or Windows CMD.
"""
import re, uuid, shutil, os, sys

PCB_IN  = r"C:\Users\sivak\OneDrive\Documents\ecg-biosensor\hardware\ECG-Biosensor-AD8232.kicad_pcb"
PCB_OUT = r"C:\Users\sivak\OneDrive\Documents\ecg-biosensor\hardware\ECG-Biosensor-AD8232-fixed.kicad_pcb"

# Auto-detect if running locally
if not os.path.exists(PCB_IN):
    here = os.path.dirname(os.path.abspath(__file__)) if '__file__' in dir() else os.getcwd()
    alt  = os.path.join(here, "ECG-Biosensor-AD8232.kicad_pcb")
    if os.path.exists(alt):
        PCB_IN  = alt
        PCB_OUT = os.path.join(here, "ECG-Biosensor-AD8232-fixed.kicad_pcb")
    else:
        print(f"[ERROR] Board not found at:\n  {PCB_IN}\n  {alt}")
        sys.exit(1)

with open(PCB_IN, 'r', encoding='utf-8') as f:
    pcb = f.read()

shutil.copy(PCB_IN, PCB_IN + ".bak")
print(f"[INFO] Loaded {len(pcb)} chars. Backup created.")

def uid(): return str(uuid.uuid4())

# ── Helpers ───────────────────────────────────────────────────────────────────

def insert_before_closing(text, block):
    text = text.rstrip()
    assert text.endswith(')'), "PCB file doesn't end with ')'"
    return text[:-1].rstrip() + '\n' + block + '\n)'

def seg(x1, y1, x2, y2, w, layer, net):
    return (f'\t(segment (start {x1} {y1}) (end {x2} {y2})'
            f' (width {w}) (layer "{layer}") (net {net}) (uuid "{uid()}"))')

# ── A. Move caps close to U1 (direct string replace on (at x y)) ─────────────
# Component (at x y) lines — replace only the line that matches exactly,
# identified by surrounding context (footprint ref on next property line).
# Strategy: split into footprint blocks, edit each, rejoin.

def reposition_fps(text, moves):
    """moves = {ref: (new_x, new_y)}"""
    # Split on footprint start markers
    # Each block: everything from (footprint ... to the next top-level (footprint or end
    parts  = re.split(r'(?=\n\t\(footprint )', text)
    result = []
    for part in parts:
        ref_m = re.search(r'property "Reference" "([^"]+)"', part)
        if ref_m and ref_m.group(1) in moves:
            ref = ref_m.group(1)
            nx, ny = moves[ref]
            # Replace the (at X Y) or (at X Y angle) line
            part = re.sub(
                r'(\(at )([0-9.-]+) ([0-9.-]+)(\))',
                lambda m: f'{m.group(1)}{nx} {ny}{m.group(4)}',
                part, count=1
            )
            print(f"[FIX A] {ref} → ({nx}, {ny})")
        result.append(part)
    return ''.join(result)

pcb = reposition_fps(pcb, {"C1": (45, 38), "C2": (48, 38), "C3": (51, 38)})

# ── B. Add J2 footprint (9-pin 2.54mm header) at (75, 45) ────────────────────
J2_X, J2_Y = 75.0, 45.0
J2_NETS = {
    1: ("VCC",     1), 2: ("GND",     3), 3: ("ECG_OUT", 6),
    4: ("LO_PLUS", 9), 5: ("LO_MINUS",8), 6: ("VCC",     1),
    7: ("REFOUT", 10), 8: ("IAOUT",  11), 9: ("",        0),
}
pad_size, drill, pitch = 1.7, 1.0, 2.54

pads = []
for n in range(1, 10):
    py = (n - 1) * pitch
    net_name, net_code = J2_NETS[n]
    shape = "rect" if n == 1 else "circle"
    net_cl = f'(net {net_code} "{net_name}") ' if net_code > 0 else ""
    pads.append(
        f'\t\t(pad "{n}" thru_hole {shape} (at 0 {py:.4f})'
        f' (size {pad_size} {pad_size}) (drill {drill})'
        f' (layers "*.Cu" "*.Mask") {net_cl}(uuid "{uid()}"))'
    )

j2_fp = '\n'.join([
    f'\t(footprint "ecg_kicad:HDR-TH_9P-P2.54-V"',
    f'\t\t(layer "F.Cu") (uuid "{uid()}")',
    f'\t\t(at {J2_X} {J2_Y})',
    f'\t\t(property "Reference" "J2"',
    f'\t\t\t(at 0 -2 0) (layer "F.SilkS") (uuid "{uid()}")',
    f'\t\t\t(effects (font (size 1 1) (thickness 0.15))))',
    f'\t\t(property "Value" "OUTPUT_HDR"',
    f'\t\t\t(at 0 25 0) (layer "F.Fab") (uuid "{uid()}")',
    f'\t\t\t(effects (font (size 1 1) (thickness 0.15))))',
    f'\t\t(fp_line (start -1.77 -0.5) (end 1.77 -0.5)'
    f' (stroke (width 0.05) (type default)) (layer "F.CrtYd") (uuid "{uid()}"))',
    f'\t\t(fp_line (start 1.77 -0.5) (end 1.77 23.36)'
    f' (stroke (width 0.05) (type default)) (layer "F.CrtYd") (uuid "{uid()}"))',
    f'\t\t(fp_line (start 1.77 23.36) (end -1.77 23.36)'
    f' (stroke (width 0.05) (type default)) (layer "F.CrtYd") (uuid "{uid()}"))',
    f'\t\t(fp_line (start -1.77 23.36) (end -1.77 -0.5)'
    f' (stroke (width 0.05) (type default)) (layer "F.CrtYd") (uuid "{uid()}"))',
] + pads + ['\t)'])

pcb = insert_before_closing(pcb, j2_fp)
print(f"[FIX B] J2 added at ({J2_X}, {J2_Y}) with 9 pins and net assignments")

# ── C. Add missing traces (10 unconnected nets from DRC) ─────────────────────
W, WP = 0.25, 0.4
traces = [
    # VCC: U1.pad13 → C3.pad1
    seg(49.87, 40.0, 61.3, 40.0,  WP, "F.Cu", 1),
    # GND: U1.EP(pad21) → U1.pad14, then to C3.pad2
    seg(48.0,  40.0, 49.87, 39.5, WP, "F.Cu", 3),
    seg(62.7,  40.0, 62.7,  39.5, WP, "F.Cu", 3),
    seg(62.7,  39.5, 49.87, 39.5, WP, "F.Cu", 3),
    # RLD: bridge existing track stub to pad4
    seg(45.9589, 41.1711, 46.13, 40.5, W, "F.Cu", 4),
    # ECG_INP: J1.pad5 → U1.pad2
    seg(25.95, 42.7, 25.95, 39.5, W, "F.Cu", 5),
    seg(25.95, 39.5, 46.13, 39.5, W, "F.Cu", 5),
    # ECG_INN: J1.pad3 → U1.pad3
    seg(28.95, 42.7, 28.95, 40.0, W, "F.Cu", 7),
    seg(28.95, 40.0, 46.13, 40.0, W, "F.Cu", 7),
    # LO_PLUS: J2.pin4 (75, 45+3*2.54=52.62) → U1.pad12
    seg(75.0, 52.62, 75.0, 40.5,  W, "F.Cu", 9),
    seg(75.0, 40.5,  49.87, 40.5, W, "F.Cu", 9),
    # LO_MINUS: J2.pin5 (75, 45+4*2.54=55.16) → U1.pad11
    seg(75.0, 55.16, 75.0, 41.0,  W, "F.Cu", 8),
    seg(75.0, 41.0,  49.87, 41.0, W, "F.Cu", 8),
    # ECG_OUT: U1.pad10 (≈49.0, 47.0) → J2.pin3 (75, 45+2*2.54=50.08)
    seg(49.0, 47.0, 49.0, 50.08,  W, "F.Cu", 6),
    seg(49.0, 50.08, 75.0, 50.08, W, "F.Cu", 6),
]
pcb = insert_before_closing(pcb, '\n'.join(traces))
print(f"[FIX C] {len(traces)} traces added for 10 unconnected nets")

# ── D. Fix board outline (replace all Edge.Cuts, add closed rectangle) ────────
# Remove every gr_line that touches Edge.Cuts layer
def strip_edge_cuts(text):
    # Match multi-line gr_line blocks containing Edge.Cuts
    pattern = re.compile(
        r'\t\(gr_line\s*\(start[^)]+\)\s*\(end[^)]+\)\s*\(stroke[^}]+?\)\s*\(layer "Edge\.Cuts"\)[^)]*\)\s*\n',
        re.DOTALL
    )
    new, n = pattern.subn('', text)
    # Also try simpler single-line format
    pattern2 = re.compile(r'\t\(gr_line[^\n]+Edge\.Cuts[^\n]+\n')
    new, n2 = pattern2.subn('', new)
    print(f"[FIX D] Removed {n+n2} existing Edge.Cuts segments")
    return new

pcb = strip_edge_cuts(pcb)
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

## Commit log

2026-05-23 Add raw vs filtered comparison plots for all 5 resting trials
2026-05-24 Add exercise trial attempts and PQRST analysis
    [exercise_trial_1.csv, resting_trial_5.csv]
2026-05-24 Complete Experiment 1 — all resting recovery HRV metrics
2026-05-27 Add improved filter visual comparison plot
2026-05-29 Replace README with complete v2.0 — no encoding issues
2026-06-01 Add Subject 3 resting trials 1-5
    [subject_3_resting_trial_1.csv, subject_3_resting_trial_2.csv, subject_3_resting_trial_3.csv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]
2026-06-01 Add Subject 4 resting trials 1-5 — multi-subject N=3 complete
    [subject_4_resting_trial_1.csv, subject_4_resting_trial_2.csv, subject_4_resting_trial_3.csv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]
2026-06-01 Add Subject 3 and Subject 4 resting trials — multi-subject N=3
    [subject_5_resting_trial_1.csv]
2026-06-01 Add Subject 3 and 4 resting trials — N=3 multi-subject pilot study complete
    [subject_5_resting_trial_1.csv]
2026-06-03 Add Apple Watch BPM validation data — N=5 paired readings
    [apple_watch_validation.csv]
2026-06-06 Add Subject 5 resting trials 1-5 — N=4 subjects 20 trials complete
    [subject_5_resting_trial_1.csv, subject_5_resting_trial_2.csv, subject_5_resting_trial_3.csv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]
2026-06-12 Add PCB layout photos and Gerber preview - Rev A
2026-06-12 Refactor ECG data processing functions
    Refactor filtering functions and update metrics calculations for improved clarity and efficiency.
2026-06-12 Pin Streamlit Cloud dependencies
2026-06-16 Add Subject 3 Apple Watch validation — N=5 paired readings
    [apple_watch_validation_subject3.csv]
2026-06-16 Add Subject 6 resting trials and Apple Watch validation
    [ECG-Biosensor-AD8232-final.kicad_pcb, apple_watch_validation_subject6.csv, ecg_biosensor3.dsn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]
2026-06-16 Fix subject 2 electrodes photo filename
2026-06-18 Add Subject 7 resting trials and Apple Watch validation — N=6 subjects complete
    [apple_watch_validation_subject7.csv, subject_7_resting_trial_1.csv, subject_7_resting_trial_2.csv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]
2026-06-18 Remove Subject 7 Apple Watch validation — resting trials retained
    [apple_watch_validation_subject7.csv]
2026-06-18 Add Subject 7 resting trials — data collection complete
    [subject_8_resting_trial_1.csv]
2026-06-18 Final Bland-Altman — Option B stratified N=30 with Subject 7 failure mode
2026-06-18 Final JSR Bland-Altman — clean stats boxes, cohort stratification
2026-06-24 Add Phase 2 photos: assembled PCB and JLCPCB shipment packaging
2026-06-24 Rename board photo to remove space in filename
2026-06-24 Add Phase 2 hardware assembly section with PCB arrival photos
2026-06-30 Change manuscript status in README
    Updated manuscript status to reflect current peer review.
2026-07-01 Update technical report v3 - PCB received, OJSS peer review status
2026-07-01 Add PCB bill of materials (BOM) CSV
    [bom.csv]
2026-07-01 Add KiCad 3D viewer render of PCB layout
2026-07-01 Fix swapped filenames: board_photo is bare PCB, board_arrival is packaging
2026-07-01 Remove old swapped PCB photos
2026-07-01 Restore PCB arrival photos with correct filenames
2026-07-01 Fix image extensions in README - board photos are .jpeg not .png
